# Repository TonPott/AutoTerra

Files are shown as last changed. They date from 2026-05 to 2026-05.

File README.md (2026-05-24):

# Automated Terrarium

Arduino Nano 33 IoT firmware project for an automated terrarium controller.

The controller is intended to monitor and control a terrarium with a small water feature. It communicates with Home Assistant over MQTT, while keeping essential hardware safety and fallback behavior local on the Arduino.

## Project Status

This repository is currently in the design and documentation phase.

Production firmware should not be implemented until the documentation set has been reviewed and accepted:

- `SPEC.md`
- `MODULES.md`
- `entity-model.md`
- `libraries.txt`
- `HA_DASHBOARD.md`
- `HA_AUTOMATIONS.md`
- `AGENTS.md`

The production firmware sketch lives under `sketches/AutoTerraController/` and is only a compileable placeholder at this stage.

## Main Goals

The controller shall:

- drive the terrarium light by IR remote commands,
- execute local fades between light presets,
- support manual light control, stand-alone light scheduling, and Home Assistant triggered scheduling,
- measure air temperature and humidity with a Sensirion SHT45,
- measure water temperature with a B3950 10K NTC thermistor,
- measure water level with a frequency-output liquid level sensor,
- control two Noctua 5 V PWM fans,
- monitor both fans by their tachometer outputs,
- locally shut down the pump on critical water level,
- verify simple light on/off state using a TCS34725 light sensor,
- keep time with a DS3231 RTC,
- store persistent configuration in the AT24C32 EEPROM on the RTC module,
- synchronize the RTC once per day from NTP,
- publish sensor values, state, availability, warnings, and faults to Home Assistant.

## Hardware Summary

Target board:

- Arduino Nano 33 IoT

Main external modules:

- DS3231 RTC module with AT24C32 EEPROM
- Sensirion SHT45 temperature/humidity sensor
- B3950 10K NTC thermistor for water temperature
- CQRobot multi-point photoelectric liquid level sensor with frequency output
- CQRobot/Adafruit-compatible TCS34725 light/color sensor
- two Noctua NF-A4x20 5V PWM fans with a shared transistor-buffered PWM line and separate tach inputs
- pump relay module using 3.3 V logic
- IR LED driver circuit for the remote-controlled lamp

## Documentation Map

- `SPEC.md` - complete functional specification
- `MODULES.md` - firmware module responsibilities and interfaces
- `entity-model.md` - Home Assistant entity model
- `HA_DASHBOARD.md` - initial dashboard design ideas
- `HA_AUTOMATIONS.md` - Home Assistant automation responsibilities
- `HARDWARE.md` - physical build, wiring, pin map, and signal-level overview
- `ROADMAP.md` - open tasks, validation work, risks, and implementation phases
- `DECISIONS.md` - accepted design decisions and rationale
- `AGENTS.md` - Codex working rules for this repository
- `libraries.txt` - required Arduino libraries and their roles
- `sketches/AutoTerraController/` - production firmware sketch and Arduino profile
- `hardware-tests/` - manual hardware validation sketches and test documentation

## Important Design Decisions

- The Arduino is the local hardware controller and safety layer.
- Home Assistant is the configuration, dashboard, and automation layer.
- The controller must remain locally safe when WiFi, MQTT, or Home Assistant is unavailable.
- Persistent data is read from EEPROM at boot and copied into RAM. During runtime, RAM is the active source of truth.
- EEPROM is written only when configuration or runtime recovery data changes.
- No custom MQTT payload model is planned for v1. Use ArduinoHA entities.
- Text-like status messages are allowed through a sensor entity because a separate test confirmed this works with the chosen Home Assistant setup.

## Local Setup

Arduino CLI setup is a one-time local machine preparation step. The setup
scripts prepare the shared Arduino CLI toolchain used by all AutoTerra
worktrees on the same machine.

Windows:

```powershell
.\scripts\setup-arduino.ps1
```

Linux / Codex Cloud / GitHub Actions:

```bash
./scripts/setup-arduino.sh
```

The setup scripts may use the network to update Arduino indexes, install the
Nano 33 IoT core, and install the libraries listed in
`sketches/AutoTerraController/sketch.yaml`.

By default, the shared Arduino CLI home is:

- Windows: `%LOCALAPPDATA%\AutoTerra\arduino-cli`
- Linux/macOS: `$HOME/.cache/autoterra/arduino-cli`

Set `AUTOTERRA_ARDUINO_HOME` to use a different shared toolchain location.
This directory is intentionally persistent across Codex worktrees.

## Compile Check

Compile checks should not download, install, or update anything. They generate
an ignored worktree-local Arduino CLI config at `.local/arduino-cli.yaml` that
points to the shared toolchain directories, then compile the selected sketch
with explicit ignored build output under `.build/` and build-cache configuration
pointing to `.arduino-cache/`.

Windows:

```powershell
.\scripts\check-arduino.ps1
```

Linux / Codex Cloud / GitHub Actions:

```bash
./scripts/check-arduino.sh
```

The active Arduino profile is `nano33iot` and targets `arduino:samd:nano_33_iot`.
Root compile checks use `sketches/AutoTerraController/` as the default production sketch. Hardware test sketches remain under `hardware-tests/` and can be compiled by setting `SKETCH=hardware-tests/<test-folder>`.

Windows hardware-test compile:

```powershell
$env:SKETCH = "hardware-tests/i2c-bus-scan"
.\scripts\check-arduino.ps1
```

Linux/macOS hardware-test compile:

```bash
SKETCH=hardware-tests/i2c-bus-scan ./scripts/check-arduino.sh
```

If a compile check reports that the Arduino toolchain is not prepared, run the
setup script once and retry the compile check.

## Cleanup

Worktree-local generated files can be removed safely with:

```powershell
.\scripts\cleanup-worktree.ps1
```

```bash
./scripts/cleanup-worktree.sh
```

The Codex App cleanup script, if configured, should use only the worktree
cleanup script. It removes `.build/`, `.arduino-cache/`, and `.local/` from the
current worktree and does not touch the shared Arduino CLI toolchain.

The shared Arduino CLI toolchain should not be removed by automatic Codex
cleanup. For manual project-end cleanup only, remove it with:

```powershell
.\scripts\cleanup-arduino-toolchain.ps1
```

```bash
./scripts/cleanup-arduino-toolchain.sh
```

These manual toolchain cleanup scripts ask for confirmation and warn that the
next setup will need to download cores and libraries again.

## Build Order

1. Finish and review documentation.
2. Create a small proof of concept for uncertain hardware or library behavior if needed.
3. Implement modules one by one.
4. Integrate Home Assistant entities.
5. Test safety and fallback behavior.
6. Tune dashboard and automations after firmware entities are stable.

Hardware tests and uploads are intentionally local tasks. CI and the provided scripts only verify that the firmware compiles.

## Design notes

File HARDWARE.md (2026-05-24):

# HARDWARE.md – Physical build and wiring overview

## Purpose

This document is the central physical wiring reference for AutoTerra.

It summarizes power domains, pin assignments, module wiring, and signal-level rules for building or reviewing the hardware. It does not replace the functional requirements in `SPEC.md`, the module responsibilities in `MODULES.md`, or the validation tracking in `ROADMAP.md`.

## System overview

Arduino Nano 33 IoT is the only target board.

The controller monitors and controls a terrarium with light, fans, water level, water temperature, air climate, RTC, EEPROM, pump relay, and Home Assistant connectivity.

The Arduino performs local hardware control and safety logic. Home Assistant provides configuration, dashboard, schedule triggers, and notifications, but pump safety and hardware-facing control remain local.

## Power domains

- A shared 5 V supply powers the fans and the Arduino Nano 33 IoT through VIN.
- All grounds must be common: supply GND, Nano GND, fan grounds, sensor grounds, relay module ground, and transistor emitter ground.
- Nano 33 IoT logic is 3.3 V.
- All signals connected directly to Nano pins must be 3.3 V compatible.
- SDA and SCL require effective pull-ups to 3.3 V.
- I2C pull-ups must not expose Nano pins to 5 V.
- The fan PWM line may be pulled up to 5 V only because it is isolated from the Nano GPIO by the 2N3904 transistor collector node.
- Fan tach pull-ups must go to 3.3 V.

## Complete pin map

```text
D2   DS3231 INT/SQW                 INPUT_PULLUP
D3   IR LED driver                  OUTPUT / handled by IRremote
D4   TCS34725 LED control           OUTPUT, default LOW = LED off, HIGH = LED on
D5   water level frequency input    INPUT_PULLUP
D6   shared fan PWM driver          OUTPUT, inverted through 2N3904
D7   TCS34725 INT                   INPUT_PULLUP, open-drain, optional / prepared
D8   DS3231 32kHz output            INPUT_PULLUP, optional / prepared
D9   fan 1 tach                     INPUT, external 10 kΩ pull-up to 3.3 V
D10  fan 2 tach                     INPUT, external 10 kΩ pull-up to 3.3 V
D11  pump relay control             OUTPUT, safe default pump off
A0   NTC water temperature          analog input
A4   I2C SDA                        DS3231 / AT24C32 / SHT45 / TCS34725
A5   I2C SCL                        DS3231 / AT24C32 / SHT45 / TCS34725
```

## I2C bus

The I2C bus is on A4/A5.

Devices on the bus:

- DS3231 RTC
- AT24C32 EEPROM on the RTC module
- SHT45 air temperature and humidity sensor
- TCS34725 light/color sensor

I2C addresses are validated during hardware and module tests. The SHT45 address may still be hardcoded in firmware later, but the tested hardware confirmed `0x44`.

### Confirmed I2C scan result

A manual I2C scan confirmed the expected external AutoTerra devices.

Confirmed external devices:

- `0x29` TCS34725 color/light sensor
- `0x44` SHT45 / SHT4x air temperature and humidity sensor
- `0x57` AT24C32 EEPROM
- `0x68` DS3231 RTC

Additional addresses seen on the Nano 33 IoT:

- `0x60` likely onboard ATECC608A secure element
- `0x6A` likely onboard LSM6DS3 IMU

These onboard addresses are expected on the Nano 33 IoT and should not be mistaken for extra external AutoTerra modules.

The bus must remain 3.3 V safe for the Nano 33 IoT.

- SDA and SCL require effective pull-ups to 3.3 V.
- The pull-ups may be provided by verified onboard module pull-ups or by external resistors.
- Do not use pull-ups to 5 V on SDA or SCL.
- If multiple breakout boards provide onboard pull-ups, verify the resulting effective pull-up resistance.
- External 4.7 kΩ pull-ups to 3.3 V are a typical starting point only if the bus does not already have suitable pull-ups.
- I2C module supply and pull-ups must not expose Nano pins to 5 V unless proper level shifting or isolation is used.

## Module wiring overview

| Module | Power | Signal pins | Notes |
|---|---|---|---|
| DS3231 + AT24C32 | 3.3 V safe module supply | A4 SDA, A5 SCL, D2 INT/SQW, D8 32kHz optional | RTC alarms use D2. AT24C32 shares I2C. D8 is prepared only. |
| SHT45 | 3.3 V safe module supply | A4 SDA, A5 SCL | Air temperature and humidity. Tested hardware confirmed address `0x44`; firmware may hardcode it later. |
| TCS34725 AngelTCS34725US / TCS34725FN | 3.3 V safe module supply | A4 SDA, A5 SCL, D4 LED, D7 INT optional | D4 LOW = LED off, HIGH = LED on. INT is open-drain and uses INPUT_PULLUP. |
| B3950 10K NTC | 3.3 V divider supply | A0 | 3.3 V -> 8.2 kΩ reference resistor -> A0 -> B3950 NTC -> GND. |
| CQRobot multi-point liquid level sensor | Sensor supply per module requirements, output must be 3.3 V safe | D5 | Frequency-output sensor, not I2C. D5 uses INPUT_PULLUP. |
| Two Noctua NF-A4x20 5V PWM fans | +5 V fan supply | D6 PWM driver, D9 fan 1 tach, D10 fan 2 tach | Shared 2N3904 PWM driver, separate tach inputs. |
| Pump relay module | Relay module supply per module requirements | D11 | D11 commands relay input. Safe default is pump off. |
| IR LED driver | Driver supply per circuit requirements | D3 | Driven by IRremote. Detailed driver circuit may be documented later. |

## Fan wiring

Fan power:

- both fan yellow wires connect to +5 V,
- both fan black wires connect to common GND.

Shared PWM driver:

- both blue PWM wires connect to the shared fan PWM collector node,
- the shared PWM collector node is pulled up to +5 V with 2.2 kΩ,
- D6 drives the 2N3904 base through 2.2 kΩ,
- 2N3904 emitter connects to GND,
- 2N3904 collector connects to the shared fan PWM node,
- 10 kΩ base pulldown connects base to GND,
- the driver is inverting.

Tach wiring:

- fan 1 green tach wire connects to D9,
- fan 2 green tach wire connects to D10,
- each tach line has its own 10 kΩ pull-up to 3.3 V,
- tach outputs must not be tied together,
- tach pull-ups must not connect to 5 V.

## Water level sensor wiring

- Signal output connects to D5.
- D5 is configured as INPUT_PULLUP.
- The sensor is a frequency-output sensor, not I2C.
- The sensor output connected to D5 must be 3.3 V compatible.

## Pump relay wiring

- Relay control input connects to D11.
- D11 is configured as OUTPUT.
- The safe default is pump off.
- Pump cutoff is local and latched.
- Firmware only commands the relay module.
- Mains wiring, isolation, enclosure, strain relief, and safety are hardware responsibilities.
- Do not assume a GPIO can drive a relay coil directly; the relay module must provide suitable driver circuitry.

## Light sensor wiring

The AngelTCS34725US / TCS34725FN module uses I2C plus LED and INT pins:

- SDA connects to A4,
- SCL connects to A5,
- LED control connects to D4,
- D4 HIGH = LED on,
- D4 LOW = LED off,
- INT connects to D7,
- INT is open-drain,
- D7 uses INPUT_PULLUP,
- INT is optional/prepared and not required for v1 logic.

## RTC and EEPROM wiring

- DS3231 and AT24C32 share I2C on A4/A5.
- DS3231 INT/SQW connects to D2 with INPUT_PULLUP.
- DS3231 32kHz output connects to D8 with INPUT_PULLUP.
- D8 is optional/prepared.
- No interrupt shall be attached to DS3231 32kHz in v1.

## Analog water temperature wiring

- B3950 10K NTC connects to A0 through a voltage divider.
- The divider uses an 8.2 kΩ upper reference resistor from 3.3 V to A0.
- The NTC divider is powered from the Nano 3.3 V domain.
- Nominal thermistor resistance is 10 kΩ.
- B value is 3950.
- Nominal temperature is 25 °C.
- AREF is not connected in v1.
- Do not connect an external 3.3 V reference to AREF unless the firmware explicitly configures and validates external analog reference use.

Wiring:

```text
3.3 V -> 8.2 kΩ -> A0 -> B3950 NTC -> GND
```

The 8.2 kΩ resistor is the upper reference leg, and the NTC is the lower leg to GND.

## IR output wiring

- IR LED driver is assigned to D3.
- D3 is handled by IRremote.
- The detailed IR LED driver circuit may be documented later if needed.
- Do not move D3 unless explicitly decided.

## Signal-level rules

- Nano 33 IoT GPIO is 3.3 V logic.
- Direct Nano inputs must not be pulled to 5 V.
- SDA and SCL require effective pull-ups to 3.3 V.
- I2C pull-ups must be 3.3 V safe and must not pull SDA or SCL to 5 V.
- External 4.7 kΩ pull-ups to 3.3 V are only a typical starting point when suitable onboard pull-ups are not already present.
- Fan tach pull-ups must be 3.3 V.
- Fan PWM pull-up may be 5 V only at the isolated transistor collector / fan PWM node.
- All grounds must be common.

## Safety notes

- Pump mains voltage must be treated as dangerous.
- Firmware documentation cannot replace safe electrical construction.
- Relay/contact rating is not the only safety requirement.
- Enclosure, isolation, strain relief, fuse/protection, cable routing, and legal/electrical safety rules must be handled outside firmware.

## Open hardware validation items

Relevant hardware checks are tracked in `ROADMAP.md`. The most important hardware-facing items are:

- 25 kHz fan PWM on Nano 33 IoT / SAMD21,
- fan PWM signal quality with both fans connected,
- fan tach readings,
- minimum fan PWM percent,
- PWM-to-RPM table,
- required water level sensor mounting height in the real tank,
- real levels for pump warning and stop,
- TCS34725 Clear-channel behavior in the actual room,
- DS3231 32kHz behavior if ever used,
- I2C bus voltage safety,
- relay wiring and mains safety.

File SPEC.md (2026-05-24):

# SPEC.md – Automated Terrarium

## 1. Scope

This document defines the target behavior of the terrarium controller firmware and its Home Assistant integration.

The project is based on an **Arduino Nano 33 IoT**. It shall operate as an autonomous hardware controller while using Home Assistant for configuration, dashboards, warnings, and scheduled events.

The document is written for a reader with beginner-to-intermediate Arduino and Home Assistant knowledge. It intentionally explains hardware roles, software behavior, and fallback cases in detail.

## 2. Core architecture

### 2.1 Normal operation

During normal operation:

- WiFi is connected.
- MQTT is connected.
- Home Assistant is available.
- The Arduino publishes all sensor and state values.
- Home Assistant provides configuration values.
- The Arduino still executes hardware-facing control locally.

At startup the Arduino shall:

1. initialize hardware modules,
2. read persistent configuration from AT24C32 EEPROM,
3. load configuration into RAM,
4. check RTC time,
5. attempt WiFi and MQTT connection,
6. publish current modes, sensor data, availability, and faults to Home Assistant,
7. resume a stored fade if applicable,
8. immediately evaluate pump safety.

### 2.2 Offline and fallback operation

If MQTT/Home Assistant is unavailable for **5 minutes**, the controller enters reduced stand-alone behavior.

In fallback mode:

- light uses the last stored stand-alone schedule,
- fan behavior uses the last stored fan mode and configuration,
- pump safety remains local,
- faults and counters are retained and republished after reconnect,
- configuration changes from Home Assistant are obviously unavailable.

Connectivity faults themselves are mostly handled in Home Assistant, but the Arduino shall maintain a connection drop / failed connection counter.

### 2.3 Timekeeping and time fallback

Primary time sources:

1. Home Assistant / NTP time
2. DS3231 RTC
3. RAM time snapshots plus uptime
4. simple timer fallback

The RTC shall be synchronized from NTP once per day. Home Assistant shall also expose a button to manually trigger synchronization.

Four times per day, the firmware shall store in RAM:

- a valid wall-clock timestamp from RTC or NTP,
- a corresponding runtime timestamp such as `millis()`.

If the RTC later fails, approximate current time can be reconstructed as:

```text
last_wall_clock_timestamp + elapsed_runtime_since_snapshot
```

If no valid RTC/NTP time is available for up to four days, this reconstructed time may be used. After four days without a valid time source, time-dependent light control falls back to a simple 24-hour timer:

```text
8 hours light using User Preset 2
16 hours off
repeat as a 24-hour cycle
```

This minimal time fallback affects light only. Safety functions such as pump cutoff and fan monitoring still run as far as their sensors allow.

## 3. Light system

### 3.1 Hardware

The terrarium lamp is controlled by IR commands that emulate the original remote control.

The existing IR LED uses pin **D3**.

IR command sending shall be non-blocking and buffered. Commands shall be spaced by a safe minimum interval.

### 3.2 Light modes

The light system has three modes:

```text
MANUAL
STANDALONE
HA_SCHEDULE
```

#### MANUAL

- Time schedules are stopped.
- Home Assistant directly controls the light.
- The Home Assistant frontend shall represent all required remote-control buttons.
- Not every button must be its own HA entity. It is acceptable to store IR commands in a named array and trigger array positions from HA buttons.
- Manual commands are not persistent.

If HA connection is lost, the next trigger starts from the current physical light state. If the Arduino restarts during manual mode and HA is unavailable, the controller uses the last applicable stand-alone preset.

#### STANDALONE

- Arduino runs a local two-event light schedule.
- Two times are configured from HA.
- Times are stored persistently in EEPROM.
- Times are also programmed into the DS3231 alarms.
- EEPROM configuration has priority over RTC alarm configuration during reconciliation.
- Day preset, night preset, and fade duration are configurable.
- Fades are calculated locally.
- If EEPROM is unavailable, hardcoded defaults with the same structure are used.

The DS3231 alarms are used for stand-alone mode only.

#### HA_SCHEDULE

Home Assistant sends scheduled light changes to the Arduino.

Each trigger contains:

- target preset,
- fade duration,
- trigger timestamp.

The Arduino:

- stores the command in RAM immediately,
- writes recovery data to EEPROM if available,
- computes and runs the fade locally,
- can resume or finish the fade after a restart.

If no fade was active before a restart, nothing is changed. The lamp is assumed to still be in its last physical state unless a fallback requires otherwise.

### 3.3 Manual override in schedule modes

Manual commands must also be possible in STANDALONE and HA_SCHEDULE.

Rules:

- a manual command interrupts any running fade,
- the manual light state remains until the next scheduled trigger,
- if the light is manually switched off, the next scheduled trigger must be able to switch it on again,
- manual commands are not persistent.

### 3.4 Preset model

Each RGBW channel has 10 steps:

```text
R: 0..10
G: 0..10
B: 0..10
W: 0..10
```

The firmware shall support:

- all factory presets,
- User Presets 1–4,
- dark/off,
- direct remote-control commands.

Some factory presets may be dynamic in the real lamp. For local fade calculation they shall be modeled as static RGBW values.

Required tables:

- static table for factory presets,
- mutable table for user presets,
- IR command table for remote-control simulation.

## 4. Light verification sensor

A TCS34725 light/color sensor is used to verify whether the lamp is broadly on or off.

The AngelTCS34725US / TCS34725FN module is connected through I2C and power, and also uses prepared optional signal pins:

- TCS34725 LED control is wired to Arduino D4,
- D4 shall be configured as `OUTPUT`,
- D4 LOW means sensor LED off,
- D4 HIGH means sensor LED on,
- the default firmware state shall keep the sensor LED off unless a measurement mode explicitly enables it,
- normal light on/off verification shall use a defined LED state, initially LED off,
- TCS34725 INT is wired to Arduino D7 and prepared for optional future use,
- the TCS34725 INT output is open-drain,
- D7 shall be configured as `INPUT_PULLUP`,
- TCS34725 INT is not required for v1 logic; v1 uses periodic and event-triggered measurements.

First firmware version:

- no full color validation,
- use the **Clear raw value** as the first on/off indicator,
- global calibration only,
- two reference values:
  - light off reference,
  - minimum on reference,
- allowed deviation: 5%.

Measurement shall happen:

- periodically,
- at fade start,
- when a target preset is reached,
- on light mode changes.

Home Assistant shall provide buttons to store the current Clear value as the off or minimum-on reference.

A light expected/actual mismatch is detected in the Arduino and reported to Home Assistant.

The room contains daylight and a ceiling light, so the TCS34725 check may be unreliable. In v1, warnings shall still be published so the behavior can be evaluated.

## 5. Climate sensor: SHT45

The SHT45 replaces the earlier SHT31 design.

Important differences:

- no hardware alert pin,
- no SHT31-style alert registers,
- thresholds are evaluated in firmware.

Requirements:

- use Sensirion arduino-i2c-sht4x library,
- SHT45 I²C address will be hardcoded later,
- measure about twice per minute,
- publish values at least once per minute,
- publish air temperature with one decimal place,
- publish humidity,
- detect and report communication or sensor errors if possible,
- mark SHT45-related entities unavailable when the sensor is unavailable.

SHT45 heater usage is not defined for v1. It remains a documented option for later evaluation, e.g. for condensation recovery, self-drying, or diagnostics.

## 6. Fan control

### 6.1 Hardware

Two Noctua NF-A4x20 5V PWM fans are used.

Design:

- one shared PWM output controls both fans,
- two tach inputs are measured separately,
- PWM driver circuit uses an inverting 2N3904 NPN transistor stage,
- tach signals are open collector,
- tach inputs use separate external 10 kΩ pull-ups to 3.3 V.

#### 6.1.1 Fan supply wiring

Both fans are powered directly from the shared 5 V supply:

- fan yellow wires connect to the +5 V supply,
- fan black wires connect to common GND,
- Arduino Nano 33 IoT is powered from the same 5 V supply through VIN.

All grounds must be common: power supply GND, Nano GND, both fan grounds, and the 2N3904 emitter.

Two NF-A4x20 5V PWM fans need about 0.2 A maximum for the fans alone. The power supply must also reserve current for the Nano, sensors, relay module, startup transients, and load peaks.

A local bulk capacitor on the 5 V rail, for example 100 µF near the fan or power distribution point, is recommended as hardware decoupling. This is not a firmware requirement.

#### 6.1.2 Shared fan PWM driver

The shared fan PWM line is driven by a 2N3904 used as an NPN open-collector style driver:

- Nano D6 connects through a 2.2 kΩ base resistor to the 2N3904 base,
- 2N3904 emitter connects to GND,
- 2N3904 collector connects to the shared fan PWM node,
- the blue PWM wires of both fans connect to this shared collector node,
- the shared fan PWM node has an external 2.2 kΩ pull-up to +5 V,
- an optional 10 kΩ base pulldown from base to GND may be used so the transistor stays off during reset.

This circuit intentionally inverts the PWM signal:

- Arduino output high -> transistor on -> fan PWM line low,
- Arduino output low or high-Z during reset -> transistor off -> fan PWM line pulled high.

Therefore `FanControl` must continue to convert effective fan percent to inverted PWM hardware duty.

The external 2.2 kΩ pull-up is intentional so the PWM line has defined edges with both fans connected and the Nano GPIO does not directly drive or sink both fan PWM inputs. The 5 V PWM line exists only at the fan PWM inputs, the pull-up, and the transistor collector. It must not be directly connected to a Nano input or output pin.

#### 6.1.3 Separate RPM/tach wiring

The fan tach signals are wired separately:

- fan 1 green tach wire connects to D9,
- fan 2 green tach wire connects to D10,
- each tach line has its own external 10 kΩ pull-up to 3.3 V,
- tach outputs must not be tied together,
- tach pull-ups must not connect to 5 V.

The tach outputs are open collector. With 3.3 V pull-ups they are compatible with Nano 33 IoT inputs.

RPM calculation should assume two pulses per revolution unless later hardware testing proves otherwise. D9 and D10 must be used as interrupt-capable or otherwise reliably sampled tach inputs according to the final Nano 33 IoT implementation approach.

#### 6.1.4 PWM frequency

Fan PWM shall target the Noctua / 4-pin-PWM typical high-frequency range around 25 kHz. The timer configuration for Nano 33 IoT / SAMD21 must be implemented intentionally; default `analogWrite()` behavior must not be assumed to produce the required fan-control frequency. The implementation must verify the actual PWM frequency during hardware bring-up.

#### 6.1.5 Protection and level notes

- Tach pull-ups go to 3.3 V to protect Nano inputs.
- The fan PWM pull-up goes to 5 V because it is a fan-control line driven only through the transistor collector and not directly connected to a Nano input or output.
- Do not connect fan tach outputs to 5 V pull-ups.
- Do not drive two fan PWM inputs directly from the Nano GPIO in this design.
- Keep common ground between Arduino and fan supply.

The firmware shall operate in effective fan percentage:

```text
0% = off
100% = full fan output
```

The hardware driver converts effective percentage to the inverted raw PWM output.

Example:

```text
effective 0%   -> hardware duty 100%
effective 40%  -> hardware duty 60%
effective 100% -> hardware duty 0%
```

The `FanControl` hardware layer shall account for the inverting driver and expose only effective fan percentage to the rest of the firmware.

### 6.2 Fan modes

Fan control has its own persistent mode:

```text
AUTO
MANUAL
```

#### AUTO

The Arduino computes fan speed locally from two four-point curves:

- air temperature to fan percent,
- air humidity to fan percent.

The higher computed value wins.

Curve behavior:

- below point 1: 0%,
- between points: linear interpolation,
- above point 4: constant at point 4 output.

Default temperature curve:

```text
26 °C -> 0%
28 °C -> 20%
30 °C -> 35%
33 °C -> 50%
```

Default humidity curve:

```text
50 %RH -> 0%
65 %RH -> 20%
75 %RH -> 30%
90 %RH -> 50%
```

#### MANUAL

Home Assistant sets the fan percentage directly.

Manual fan mode requirements:

- the mode is persistent,
- the last manual percent is persistent,
- the mode is retained during HA/MQTT loss,
- sensor faults are reported but do not automatically override manual mode to 100%.

### 6.3 Fan diagnostics

The firmware shall publish:

- shared effective fan PWM percent,
- fan 1 RPM,
- fan 2 RPM,
- fan 1 fault,
- fan 2 fault,
- optional RPM mismatch warning.

A fixed calibration table will be provided later:

```text
effective PWM percent -> expected RPM
```

The table applies to both fans initially and is not editable from Home Assistant.

Minimum PWM starts at 15% and must be evaluated in real hardware.

No automatic fan restart sequence is required.

## 7. Water temperature

A B3950 10K NTC thermistor measures water temperature.

Requirements:

- connected to A0 analog input,
- B3950 10K NTC voltage divider documented in `HARDWARE.md`,
- nominal thermistor resistance: 10 kΩ,
- B value: 3950,
- nominal temperature: 25 °C,
- use NTC_Thermistor library,
- publish all available temperature units:
  - Celsius,
  - Fahrenheit,
  - Kelvin.

The frontend later decides which value is displayed.

## 8. Water level

### 8.1 Sensor

The liquid level sensor is **not I²C-based**. It outputs a square wave.

Nominal frequencies:

```text
without liquid: 20 Hz
Level 1:        50 Hz
Level 2:       100 Hz
Level 3:       200 Hz
Level 4:       400 Hz
```

The sensor shall be read using a digital interrupt-capable input with INPUT_PULLUP.

The assigned pin is **D5**, because D2 is used for RTC interrupt and D3 is used for IR.

### 8.2 Measurement and publication

The level is evaluated once per minute.

Normal HA publication:

- water level in mm.

Optional diagnostics during setup, calibration, or troubleshooting:

- internal level,
- raw frequency.

Raw frequency is not required for the normal dashboard and should not be considered part of the regular user-facing entity set unless calibration or troubleshooting requires it.

### 8.3 Mechanical calibration

Home Assistant configures the distance from sensor top edge to tank bottom. This value must be stored in Arduino EEPROM because the Arduino calculates the water height.

Sensor geometry:

```text
total sensor height: 78.2 mm
Level 4 is 24.4 mm below sensor top edge
each lower level is 16 mm below the previous one
```

Pump cutoff is based on **level**, not mm.

### 8.4 Stability rule

Level changes between noncritical levels are debounced over a long period.

Example:

- official level is Level 4,
- Level 3 is measured,
- timestamp is stored,
- if Level 4 is measured again, the Level 3 candidate is discarded,
- if Level 4 is not measured for 6 hours, Level 3 becomes official.

Exception:

- without liquid / 20 Hz triggers pump cutoff immediately.

Leak warning:

- if the next lower level is reached during the 6-hour waiting period, publish a possible leak / fast-loss warning to Home Assistant.

## 9. Pump safety

The relay module is considered Arduino-ready and uses 3.3 V logic.

The pump is controlled locally for safety.

Rules:

- critical water level immediately shuts off pump,
- pump cutoff is latched,
- no automatic restart after cutoff,
- manual release is required,
- when water level sensor is unavailable, pump is turned off,
- Home Assistant may manually re-enable the pump despite sensor unavailability,
- this sensor-failure override is **not persistent**,
- after every Arduino restart, the user must confirm pump enable again while the sensor remains unavailable.

Home Assistant shall show a visible warning next to the pump switch when the water level sensor is unavailable.

Mains voltage safety must be documented separately. The firmware can command the relay, but safe wiring, isolation, enclosure, and strain relief are hardware requirements.

## 10. RTC and EEPROM

### 10.1 DS3231

The DS3231 provides local time and two alarms.

Requirements:

- DS3231 INT/SQW pin uses INPUT_PULLUP,
- assigned pin: D2,
- DS3231 INT/SQW remains on D2 and is used for stand-alone alarm triggers,
- DS3231 32kHz output is wired to Arduino D8 and prepared for optional future use,
- D8 shall be configured as INPUT_PULLUP,
- the 32kHz signal is not used by v1 logic and no interrupt shall be attached by default,
- if 32kHz is enabled later, it must be handled carefully because it is a high-frequency signal,
- alarms are used for stand-alone light mode,
- RTC is synchronized from NTP daily,
- HA exposes a manual sync button.

### 10.2 AT24C32 EEPROM

The AT24C32 is accessed using JC_EEPROM.

Design rule:

```text
EEPROM is persistent storage.
RAM is the active runtime source of truth.
```

At boot:

- read EEPROM,
- validate minimal header,
- copy data to RAM.

At runtime:

- use RAM values,
- update RAM immediately on HA changes,
- write EEPROM only when configuration or recovery data changes.

If EEPROM becomes unavailable during operation:

- report error,
- continue with RAM configuration.

If EEPROM is unavailable at boot:

- use hardcoded defaults,
- accept HA configuration if HA becomes available,
- operate non-persistently until EEPROM recovers.

### 10.3 EEPROM validation

Use a minimal header only:

```text
magic
version
length
```

No CRC.

Reason:

- CRC would be stored in the same EEPROM and may itself be corrupted,
- false invalidation of otherwise valid data is possible,
- implementation complexity is not justified for v1.

Use two logical blobs:

- Config blob,
- Runtime blob.

## 11. Persistence data

### 11.1 Persistent configuration

Store:

- light mode,
- fan mode,
- last manual fan percent,
- stand-alone schedule times,
- stand-alone day/night presets,
- stand-alone fade duration,
- fan curves,
- minimum PWM,
- temperature warning thresholds,
- water level calibration,
- pump cutoff threshold / level,
- light sensor calibration values,
- user presets.

### 11.2 Runtime recovery data

Store:

- whether a fade is active,
- fade start time,
- fade duration,
- fade start state,
- fade target state,
- last relevant light state,
- last valid time snapshot if needed,
- offline fault counters if HA was unreachable.

### 11.3 Not persistent

Do not persist:

- regular sensor measurements,
- debug flag,
- one-off manual light commands,
- pump sensor-failure override,
- transient runtime states not needed for recovery.

## 12. Faults, warnings, diagnostics, and availability

### 12.1 Definitions

A fault is a state that affects local operation or disables a module.

A warning is a state that should be visible but may not require local intervention.

A diagnostic value explains system state.

### 12.2 Self-diagnosis

Each module shall provide a health / availability state.

I²C problems are detected by checking each I²C transaction or module library return value. A central I²C health check may also be added, but individual module checks remain required.

When a module is known to be unavailable, its corresponding HA entities shall be marked unavailable if the chosen entity type supports availability.

### 12.3 Fault examples

Faults:

- SHT45 unavailable,
- RTC unavailable,
- EEPROM unavailable,
- TCS34725 unavailable,
- NTC open/short/unavailable,
- water level sensor unavailable,
- pump cutoff active,
- fan 0 RPM while expected to run.

Warnings:

- light expected/actual mismatch,
- water level one level before critical,
- RPM mismatch,
- water temperature limits,
- fast water-level drop.

Diagnostics:

- last time sync source,
- last time sync age,
- connection drop counter,
- fallback mode,
- module availability.

Hardware fault entities must not be automatically cleared only because HA reconnects. Current fault state must be republished after reconnect.

## 13. Home Assistant role

Home Assistant is responsible for:

- configuration,
- dashboards,
- warnings/notifications,
- HA schedule mode,
- water-level calibration,
- light sensor calibration,
- RTC manual sync button.

Home Assistant automations handle:

- HA light schedule triggers,
- calibration workflows,
- warning notifications,
- frontend display.

The Arduino remains responsible for:

- hardware signal processing,
- pump safety,
- fan PWM generation and RPM measurement,
- light IR output,
- local fades,
- fallback behavior.

No custom MQTT payload model shall be used in v1. Use ArduinoHA entities.

A previous isolated test confirmed that a sensor entity can be used successfully for text-like status output with the selected ArduinoHA setup.

## 14. Suggested pin map

```text
D2   DS3231 INT/SQW                 INPUT_PULLUP
D3   IR LED driver                  OUTPUT / handled by IRremote
D4   TCS34725 LED control           OUTPUT, default LOW = LED off, HIGH = LED on
D5   water level frequency input    INPUT_PULLUP
D6   shared fan PWM driver          OUTPUT, inverted through 2N3904
D7   TCS34725 INT                   INPUT_PULLUP, open-drain, optional / prepared
D8   DS3231 32kHz output            INPUT_PULLUP, optional / prepared
D9   fan 1 tach                     INPUT, external 10 kΩ pull-up to 3.3 V
D10  fan 2 tach                     INPUT, external 10 kΩ pull-up to 3.3 V
D11  pump relay control             OUTPUT, safe default pump off
A0   NTC water temperature          analog input
A4   I2C SDA                        DS3231 / AT24C32 / SHT45 / TCS34725
A5   I2C SCL                        DS3231 / AT24C32 / SHT45 / TCS34725
```

This is the current intended pin map. Pin assignments may change only through an explicit design update.

General hardware note:

- all logic signals connected directly to the Nano 33 IoT must be 3.3 V compatible,
- I2C bus must be 3.3 V safe and must have effective pull-ups to 3.3 V,
- I2C module supply and pull-ups must not expose Nano pins to 5 V unless proper level shifting or isolation is used.

## 15. Documentation-first implementation rule

Before firmware implementation, generate and review:

- `SPEC.md`,
- `MODULES.md`,
- `entity-model.md`,
- `AGENTS.md`,
- `libraries.txt`,
- `HA_DASHBOARD.md`,
- `HA_AUTOMATIONS.md`.

`Credentials.example.h` is created together with the first WiFi/MQTT implementation. It should contain only credentials that are actually needed by the implemented connectivity layer. Until connectivity code exists, credential fields should not be guessed.

Firmware implementation starts only after the documentation is accepted.

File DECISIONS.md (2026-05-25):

# DECISIONS.md – AutoTerra design decisions

## Purpose

This document records important AutoTerra design decisions and the reasoning behind them.

It is not a commit changelog. It exists to help future contributors understand why the current design is shaped the way it is.

## Decision format

Decision entries use this structure:

Title line:
`## YYYY-MM-DD – Decision title`

Status:
`Accepted`

Decision:
A short description of the decision.

Reason:
Why this decision was made.

Consequences:
What this means for the project.

## Accepted decisions

## 2026-05-16 – Documentation-first workflow before firmware implementation

Status:
Accepted

Decision:
AutoTerra will complete and review the core documentation set before production firmware implementation starts.

Reason:
The controller combines hardware safety, persistence, Home Assistant integration, fallback behavior, and several sensors. Defining the intended behavior first reduces accidental implementation drift.

Consequences:
Firmware work must follow `SPEC.md`, `MODULES.md`, `entity-model.md`, `libraries.txt`, `HA_DASHBOARD.md`, `HA_AUTOMATIONS.md`, and `AGENTS.md`. Open work and validation tasks belong in `ROADMAP.md`.

## 2026-05-16 – Arduino Nano 33 IoT as the only target board

Status:
Accepted

Decision:
The only target board for v1 is Arduino Nano 33 IoT.

Reason:
The selected hardware, WiFi support, pin plan, and SAMD21 behavior are specific to this board.

Consequences:
No AVR, Arduino Mega, or generic compatibility layer should be added unless the decision is explicitly revisited.

## 2026-05-16 – SHT45 replaces SHT31; no hardware alert mode

Status:
Accepted

Decision:
AutoTerra uses the Sensirion SHT45 for air temperature and humidity, and does not use SHT31-style hardware alert mode.

Reason:
The selected SHT45 design does not provide the earlier SHT31 alert-register workflow.

Consequences:
Threshold evaluation and fault reporting belong in firmware logic, not hardware alert pins or SHT31 alert registers.

## 2026-05-16 – Home Assistant handles configuration and dashboards; Arduino keeps local hardware safety

Status:
Accepted

Decision:
Home Assistant is responsible for configuration, dashboards, notifications, and schedule triggers, while the Arduino remains responsible for local hardware safety and fallback behavior.

Reason:
The controller must remain safe when WiFi, MQTT, or Home Assistant is unavailable.

Consequences:
Pump cutoff, sensor reads, fan PWM generation, RPM measurement, IR output, local fades, and fallback logic must run locally on the Arduino.

## 2026-05-16 – No custom MQTT payload model for v1; use ArduinoHA entities

Status:
Accepted

Decision:
AutoTerra v1 will use ArduinoHA entities instead of a custom MQTT payload architecture.

Reason:
ArduinoHA provides Home Assistant discovery and entity abstractions that match the intended integration model.

Consequences:
Entity design belongs in `entity-model.md`. Fan curves and configuration values may use multiple standard entities rather than custom packed MQTT payloads.

## 2026-05-16 – Text-like status output via sensor entity is accepted

Status:
Accepted

Decision:
Text-like status output through a sensor entity is accepted for v1.

Reason:
A separate proof-of-concept test confirmed that this works in the selected Home Assistant setup.

Consequences:
The firmware may expose system status text through an ArduinoHA sensor entity, and this premise should be preserved in documentation.

## 2026-05-16 – AT24C32 EEPROM is persistent storage; RAM is runtime source of truth

Status:
Accepted

Decision:
The AT24C32 EEPROM stores persistent configuration and recovery data, but RAM is the active source of truth after boot.

Reason:
Constant EEPROM reads are unnecessary and would make runtime behavior more fragile and slower.

Consequences:
The firmware reads EEPROM at boot, copies valid data into RAM, updates RAM immediately on changes, and writes EEPROM only when persistent data changes.

## 2026-05-16 – EEPROM validation uses magic, version, and length, but no CRC

Status:
Accepted

Decision:
EEPROM blobs use minimal validation fields: `magic`, `version`, and `length`. CRC is not used for v1.

Reason:
A CRC stored in the same EEPROM can itself be corrupted, and the extra complexity is not justified for the first version.

Consequences:
The firmware should reject obviously incompatible blobs but should not implement CRC validation unless this decision is revisited.

## 2026-05-16 – Persistent storage uses a config blob and a runtime blob

Status:
Accepted

Decision:
Persistent storage is split into a configuration blob and a runtime recovery blob.

Reason:
Long-lived user configuration and short-lived recovery state have different lifecycles and should not be conflated.

Consequences:
Persistence code must keep configuration values separate from fade recovery, time snapshots, and other runtime recovery data.

## 2026-05-16 – Fan control supports AUTO and MANUAL modes with persistent manual settings

Status:
Accepted

Decision:
Fan control supports AUTO and MANUAL modes. Fan mode and manual fan percent are persistent.

Reason:
Manual fan control must remain predictable during Home Assistant or MQTT loss.

Consequences:
The firmware must retain manual fan mode and the last manual percent across restart and communication loss.

## 2026-05-16 – Fan PWM uses an inverting 2N3904 driver and effective fan percent

Status:
Accepted

Decision:
Internal fan logic uses effective fan percent, while `FanControl` converts that value to the inverted PWM duty required by the external driver circuit. The shared fan PWM signal is driven through an inverting 2N3904 NPN transistor stage. The shared fan PWM node uses a 2.2 kΩ pull-up to +5 V, and the Nano GPIO must not directly drive the two fan PWM inputs. Fan tach pull-ups are separate 10 kΩ resistors to 3.3 V.

Reason:
The transistor stage protects the Nano GPIO from the 5 V fan PWM line, supports both fan PWM inputs from one shared signal, and keeps inversion isolated at the hardware boundary.

Consequences:
`FanControl` owns the conversion from effective fan percent to inverted PWM hardware duty. Tach inputs remain separate and use 3.3 V pull-ups to protect Nano inputs.

## 2026-05-25 – Use analogWrite-based fan PWM for v1

Status:
Accepted

Decision:
AutoTerra v1 uses Arduino `analogWrite()`-based fan PWM on D6 through the inverting 2N3904 driver.

Reason:
`analogWrite()`-based PWM worked reliably with the inverting 2N3904 driver, and both fan tach inputs worked. Manual hardware tests measured minimum startup and minimum stable running values. A/B testing showed no audible difference between `analogWrite()` and approximately 25 kHz PWM. The approximately 25 kHz mode requires taking ownership of TCC0 on the Nano 33 IoT, changes the PWM-to-RPM response, and would require separate calibration.

Consequences:
The v1 fan calibration table is based on `analogWrite()` results. Custom approximately 25 kHz fan PWM remains a future option. If approximately 25 kHz PWM is enabled later, the fan calibration table must be repeated or confirmed. TCC0 ownership and IR regression testing remain relevant only if approximately 25 kHz PWM is adopted later.

## 2026-05-16 – SHT/I²C errors do not automatically force MANUAL fan mode to 100%

Status:
Accepted

Decision:
SHT or I²C errors are reported, but they do not automatically override MANUAL fan mode to 100%.

Reason:
Manual fan mode is an intentional user-controlled state and should not be unexpectedly replaced by fault behavior unless requirements change.

Consequences:
Faults must be visible in Home Assistant, but MANUAL fan mode remains manual during these errors.

## 2026-05-16 – Pump cutoff is local and latched; sensor-failure override is not persistent

Status:
Accepted

Decision:
Pump cutoff is enforced locally and latched. Home Assistant may manually re-enable the pump during water sensor failure, but that override is not persistent.

Reason:
Pump safety must not depend on network availability, and sensor-failure override should require conscious confirmation after every restart.

Consequences:
The firmware must not auto-restart the pump after cutoff and must clear sensor-failure override on Arduino restart.

## 2026-05-16 – Water level downward changes use 6-hour stabilization except without liquid

Status:
Accepted

Decision:
Official downward changes between noncritical water levels require a 6-hour stabilization period, while `without liquid` triggers immediate pump cutoff.

Reason:
Normal water movement may cause transient lower readings, but no-liquid state is safety-critical.

Consequences:
`LiquidSensor` must track candidate lower levels over time and `PumpSafety` must react immediately to `without liquid`.

## 2026-05-16 – Light fallback without valid time uses 8 h User Preset 2 and 16 h off

Status:
Accepted

Decision:
If no valid time source is available beyond the allowed fallback period, light control uses an 8-hour on / 16-hour off timer with User Preset 2.

Reason:
The terrarium should retain a simple, predictable light cycle even without RTC, NTP, or Home Assistant time.

Consequences:
This minimal timer fallback applies to light behavior only and does not replace other safety logic.

## 2026-05-16 – TCS34725 v1 uses global Clear-channel on/off validation only

Status:
Accepted

Decision:
The first TCS34725 implementation uses the Clear raw channel for broad light on/off validation, not full color validation.

Reason:
Room daylight and ceiling light may make full validation unreliable, and the first version only needs a broad expected/actual mismatch check.

Consequences:
Firmware should publish warnings for mismatches, but full RGB/lux/color-temperature validation is deferred.

## 2026-05-16 – Credentials example is deferred until first WiFi/MQTT implementation

Status:
Accepted

Decision:
`Credentials.example.h` will be created with the first WiFi/MQTT implementation, not during documentation-only setup.

Reason:
The exact credential structure should follow the actual WiFi and MQTT implementation interfaces. Until connectivity code exists, credential fields should not be guessed.

Consequences:
Documentation may mention the planned credentials example, but this documentation-only phase does not need to create it yet. The file should contain only credentials that are actually needed by the implemented connectivity layer.

## 2026-05-17 – Optional TCS34725 and DS3231 signal lines are wired and reserved from the start

Status:
Accepted

Decision:
Optional TCS34725 LED/INT and DS3231 32kHz lines are wired and reserved from the start. D4 is TCS34725 LED control with LOW = LED off and HIGH = LED on. D7 is TCS34725 INT prepared input with `INPUT_PULLUP` because INT is open-drain. D8 is DS3231 32kHz prepared input with `INPUT_PULLUP`.

Reason:
Wiring optional signals from the start avoids later rewiring if these functions become useful during calibration, diagnostics, or future firmware versions.

Consequences:
These functions may be initialized safely even when not actively used in v1. TCS34725 INT and DS3231 32kHz remain optional prepared inputs; v1 does not depend on them.

## Superseded decisions

No superseded decisions are recorded yet.

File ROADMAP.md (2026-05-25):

# ROADMAP.md – AutoTerra implementation roadmap

## Purpose

This document tracks open tasks, validation work, implementation phases, known risks, and deferred decisions for AutoTerra.

It does not redefine current requirements. The target behavior remains documented in `SPEC.md`, `MODULES.md`, `entity-model.md`, `HA_DASHBOARD.md`, `HA_AUTOMATIONS.md`, and `libraries.txt`.

## Documentation phase

- Keep `SPEC.md`, `MODULES.md`, and `entity-model.md` as current target-state documents.
- Keep `AGENTS.md` as Codex working rules.
- Keep `README.md` as the project overview and documentation map.
- Keep `DECISIONS.md` as the accepted design rationale and design history.
- Avoid scattering TODOs inside requirement documents when a task belongs in `ROADMAP.md`.
- Move validation tasks, open implementation work, known risks, and deferred decisions into this document unless the uncertainty is itself part of the requirement.

## Pre-implementation validation tasks

- Verify ArduinoHA text-like sensor behavior is already completed successfully, but keep the result documented as an accepted premise.
- Confirm that fan PWM driver inversion is handled only inside `FanControl`.
- Use the first `hardware-tests/fan-pwm-tach` sketch to validate wiring, driver inversion, and tach reading with `analogWrite()` only.
- Use the separate `hardware-tests/fan-pwm-calibration` sketch to collect minimum startup, minimum stable running, and 5%-step `analogWrite()` RPM data.
- Use the separate `hardware-tests/fan-pwm-frequency-ab` sketch to compare Arduino `analogWrite()` with approximately 25 kHz PWM when the local D6 timer setup is safe.
- Validate that the selected ArduinoHA entity types work as expected for fan, select, number, binary sensor, button, switch, and text-like sensor output.
- Validate integrated RTC scheduling behavior around RTClib alarms after `RtcClock` is implemented.
- Confirm the final pin map against the real hardware layout before firmware implementation.
- Verify whether normal light verification should run with the TCS34725 LED off, on, or in a controlled measurement sequence.
- Verify TCS34725 INT behavior on D7 if future threshold or interrupt use is desired.
- Verify DS3231 32kHz output behavior on D8 before using it for timing or diagnostics.
- Confirm that no connected module exposes Nano 33 IoT pins to 5 V logic levels.
- Revisit `NTC_Thermistor` version selection when version 2.1.1 or later is available through Arduino Library Manager.
- Create `Credentials.example.h` together with the first WiFi/MQTT implementation.
- Ensure `Credentials.example.h` contains only credentials that are actually needed by the implemented connectivity layer.
- Do not guess credential fields before connectivity code exists.

## Firmware implementation phases

- Phase 1: compileable project skeleton under `sketches/AutoTerraController/`.
- Phase 2: infrastructure modules: Debug, Config, Types, TimeSync, Persistence.
- Phase 3: sensor modules: SHT45, NTC, LiquidSensor, TCS34725.
- Phase 4: actuator modules: IRControl, Fade, LightRuntime, FanControl, PumpSafety.
- Phase 5: HomeAssistantBridge entities and command handling.
- Phase 6: fault handling, fallback behavior, reconnect republishing.
- Phase 7: integration testing and dashboard/automation refinement.

## Hardware validation tasks

- Manual hardware validation sketches and test documentation live under [`hardware-tests/`](hardware-tests/README.md).
- Integrate the v1 fan PWM-to-RPM calibration table from the accepted `analogWrite()` results.
- Test fan tach readings with separate external 10 kΩ pull-ups to 3.3 V.
- Test the water level sensor frequencies in the real tank.
- Evaluate the 6-hour stabilization rule with the real water surface behavior.
- Test the immediate pump cutoff at the `without liquid` level.
- Test the TCS34725 Clear-channel light on/off detection in the actual room.
- Test NTC readings with the chosen 8.2 kΩ reference resistor voltage divider.
- Evaluate analog reference strategy only if NTC readings show unacceptable noise or drift.
- Confirm relay module wiring and mains safety outside firmware scope.

## Validated findings

- Manual I2C bus scan completed successfully.
- Confirmed external I2C addresses:
  - `0x29` TCS34725 color/light sensor
  - `0x44` SHT45 / SHT4x air temperature and humidity sensor
  - `0x57` AT24C32 EEPROM
  - `0x68` DS3231 RTC
- Observed expected onboard Nano 33 IoT I2C addresses:
  - `0x60` likely ATECC608A secure element
  - `0x6A` likely LSM6DS3 IMU
- I2C voltage-safety validation remains separate from the successful bus scan unless SDA/SCL levels are measured directly.
- Manual fan PWM/tach `analogWrite()` bring-up completed successfully.
- Confirmed D6 inverting fan PWM control behavior, separate D9/D10 tach interrupt readings, and plausible RPM measurements for both Noctua NF-A4x20 5V PWM fans.
- Observed effective 0% stopping both fans after spin-down and effective 100% producing approximately 4,860-5,040 RPM across the two fans in the initial run.
- Manual fan PWM calibration `analogWrite()` run completed successfully.
- Observed analogWrite-based minimum startup for both fans at 10% effective PWM; fan 1 alone started at 8%, fan 2 did not.
- Observed analogWrite-based minimum stable running for both fans at 8% effective PWM after spin-up; fan 1 alone kept running at 5%, fan 2 did not.
- Collected 5%-step analogWrite-based RPM data from 0% through 100%; this data is documented in `hardware-tests/fan-pwm-calibration/README.md`.
- Manual fan PWM frequency A/B test completed successfully in both `analogWrite()` and local approximately 25 kHz TCC0 modes.
- Observed approximately 25 kHz mode producing lower RPM than `analogWrite()` through much of the low-to-mid range, similar RPM at 75%, and slightly higher RPM at 100% in the A/B run.
- Observed no audible difference in sound profile or volume between `analogWrite()` and approximately 25 kHz PWM during the A/B test.
- v1 decision: `analogWrite()`-based fan PWM is accepted.
- Custom approximately 25 kHz fan PWM remains a future option only if noise or compatibility problems appear.
- Manual DS3231 + AT24C32 test completed successfully.
- Confirmed DS3231 RTC time readout, RTClib Alarm1 setup, Alarm1 flag reporting, D2 INT/SQW active-LOW alarm behavior, and D2 returning HIGH after clearing and disabling Alarm1.
- Confirmed AT24C32 EEPROM write/read verification at test offset `0x0F00`.
- Observed D8 32kHz prepared input as HIGH during the test; 32kHz pulse counting was intentionally not performed.

## Home Assistant validation tasks

- Validate MQTT discovery behavior for all planned ArduinoHA entities.
- Validate fan, select, number, binary sensor, button, and switch entities in the target Home Assistant installation.
- Validate text-like status output through a sensor entity remains reliable after integration.
- Validate state republishing after MQTT reconnect.
- Validate that module availability and fault entities behave clearly in the dashboard.
- Validate the pump sensor-failure warning near the pump control before allowing manual override workflows.
- Defer final Lovelace dashboard and automation YAML until entity names and types are stable.

## Known technical risks

- Custom approximately 25 kHz fan PWM would require low-level timer configuration and TCC0 ownership if revisited.
- TCS34725 on/off detection may be unreliable due to daylight and room lighting.
- Water level signal may fluctuate because of pump-induced waves.
- EEPROM is not continuously read during runtime; RAM is the source of truth after boot.
- `NTC_Thermistor` version selection may need revisiting.
- Production RTC scheduling still needs integrated validation even though the standalone RTClib Alarm1 / D2 behavior passed.
- ArduinoHA entity behavior may differ between simple proof-of-concept tests and the fully integrated device.
- Pump safety depends on correct external relay wiring, enclosure, isolation, and mains handling, which firmware cannot guarantee.

## Deferred decisions

- Whether approximately 25 kHz fan PWM should be revisited if noise or compatibility problems appear.
- Exact SAMD21 timer configuration and TCC0 ownership strategy if approximately 25 kHz fan PWM is adopted later.
- Final production fan PWM-to-RPM table integration from the accepted `analogWrite()` calibration data.
- Exact fallback behavior for AUTO fan mode when SHT45 is unavailable.
- Exact Home Assistant UI layout after entities are implemented and visible.
- Exact RTC alarm reconciliation behavior after `RtcClock` integration.
- Final credentials example structure when WiFi and MQTT code is introduced.

## Out of scope for v1

- Custom MQTT payload architecture.
- Full color validation with TCS34725.
- Automatic fan restart attempts.
- NeoPixel alert display.
- AVR or Arduino Mega compatibility.
- Persisting one-off manual light commands.
- Persisting pump sensor-failure override.
- EEPROM CRC validation.

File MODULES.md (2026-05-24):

# MODULES.md – Firmware module design

This document describes the intended firmware modules for the Terrarium controller.

The goal is clear module boundaries. `AutoTerraController.ino` should coordinate modules but not contain hardware or business logic.

## 1. Module overview

```text
sketches/AutoTerraController/AutoTerraController.ino

Config.h / Config.cpp
Types.h
Debug.h
Credentials.h

RtcClock.h / RtcClock.cpp
TimeSync.h / TimeSync.cpp
Persistence.h / Persistence.cpp
ModeManager.h / ModeManager.cpp
FaultManager.h / FaultManager.cpp

IRMap.h / IRMap.cpp
IRControl.h / IRControl.cpp
Fade.h / Fade.cpp
LightRuntime.h / LightRuntime.cpp
LightSensorTcs34725.h / LightSensorTcs34725.cpp

Sht45Sensor.h / Sht45Sensor.cpp
WaterTempNtc.h / WaterTempNtc.cpp
LiquidSensor.h / LiquidSensor.cpp
FanControl.h / FanControl.cpp
PumpSafety.h / PumpSafety.cpp

WiFiManager.h / WiFiManager.cpp
HomeAssistantBridge.h / HomeAssistantBridge.cpp
```

## 2. `AutoTerraController.ino`

Responsibilities:

- initialize all modules,
- call `begin()` methods,
- call periodic `update()` methods,
- keep loop non-blocking,
- avoid hardware-specific logic.

`AutoTerraController.ino` shall not:

- directly parse Home Assistant commands,
- directly read sensors except for temporary diagnostics,
- directly manipulate EEPROM,
- directly contain fallback state machine logic.

## 3. `Config.*`

Responsibilities:

- pin assignments,
- default intervals,
- default fan curves,
- default light schedule,
- default pump behavior,
- compile-time options,
- non-secret constants.

Do not store WiFi or MQTT passwords here. Use `Credentials.h`.

## 4. `Types.h`

Responsibilities:

- shared enums,
- shared structs,
- small data transfer structures,
- persistent config and runtime structure declarations.

Expected types:

- `LightMode`
- `FanMode`
- `PresetId`
- `RgbwLevel`
- `LightPreset`
- `FanCurvePoint`
- `FanCurve`
- `PersistentConfig`
- `PersistentRuntime`
- `FaultFlags`
- `ModuleAvailability`

## 5. `Debug.h`

Responsibilities:

- provide debug macros,
- make debug compile-time controlled,
- never persist debug state,
- allow module-prefixed debug messages.

Suggested macros:

```cpp
DBG_PRINT(...)
DBG_PRINTLN(...)
DBG_PRINTF(...)
DBG_MODULE(moduleName, message)
```

Debug output is useful for development but cannot be required for normal operation.

## 6. `RtcClock.*`

Responsibilities:

- initialize DS3231,
- own DS3231 INT/SQW on D2,
- reserve and prepare DS3231 32kHz input on D8,
- read current time,
- configure two DS3231 alarms for stand-alone light mode,
- read and clear alarm flags,
- report RTC availability,
- detect invalid time if possible.

The RTC alarm line uses `INPUT_PULLUP`.

The DS3231 alarms are only for stand-alone mode.

The DS3231 32kHz input on D8 is optional and prepared only. `RtcClock` shall not attach a 32kHz interrupt in v1 and shall keep 32kHz handling optional.

## 7. `TimeSync.*`

Responsibilities:

- synchronize RTC from NTP once per day,
- handle manual sync request from Home Assistant,
- keep RAM time snapshots four times per day,
- provide fallback time from last timestamp plus uptime,
- expose last sync source and sync age.

Time source priority:

1. HA/NTP
2. DS3231 RTC
3. RAM timestamp + `millis()`
4. 8h on / 16h off timer fallback for light only

## 8. `Persistence.*`

Responsibilities:

- manage AT24C32 EEPROM using JC_EEPROM,
- read persistent blobs at boot,
- validate minimal headers,
- copy EEPROM data into RAM config/runtime,
- write EEPROM on changes,
- avoid constant EEPROM reads during runtime.

Persistent storage model:

- Config blob
- Runtime blob

Header:

```text
magic
version
length
```

No CRC.

Runtime rule:

```text
RAM is the active source of truth.
EEPROM is only boot source and persistent backup.
```

## 9. `ModeManager.*`

Responsibilities:

- track active light mode,
- track active fan mode,
- detect HA timeout,
- switch to stand-alone fallback after 5 minutes,
- expose current fallback state,
- coordinate mode changes without duplicating module logic.

Important:

- light mode and fan mode are separate.
- fan manual mode remains active during HA loss.
- manual light commands are not persistent.

## 10. `FaultManager.*`

Responsibilities:

- collect faults from all modules,
- distinguish faults, warnings, and diagnostics,
- expose module availability,
- decide which local reactions are required,
- keep faults latched when appropriate,
- republish current fault state after HA reconnect.

FaultManager shall not hide hardware faults just because communication has recovered.

## 11. `IRMap.*`

Responsibilities:

- store IR address and command codes,
- store remote-button table,
- store factory preset command mapping,
- store user preset command mapping if applicable.

No timing or send logic belongs here.

## 12. `IRControl.*`

Responsibilities:

- initialize IR output,
- queue IR commands,
- send commands non-blockingly,
- enforce minimum command spacing,
- report buffer overflow.

D3 is currently assigned to the IR LED.

## 13. `Fade.*`

Responsibilities:

- compute local fade between RGBW states,
- use RGBW levels 0..10,
- support resume from elapsed time,
- report fade progress and completion,
- request IR commands through `IRControl`.

Fade does not decide why a fade starts. That belongs to LightRuntime or Schedule handling.

## 14. `LightRuntime.*`

Responsibilities:

- implement light modes,
- handle manual commands,
- handle stand-alone triggers,
- handle HA schedule triggers,
- store fade recovery data,
- decide when to use fallback,
- interact with TCS34725 validation.

Manual command behavior:

- interrupts active fade,
- lasts until next scheduled trigger,
- is not persistent.

HA schedule behavior:

- store start time, target preset, duration, start state, target state,
- resume or complete after restart if runtime data is available.

## 15. `LightSensorTcs34725.*`

Responsibilities:

- initialize TCS34725,
- own TCS34725 LED control on D4,
- initialize D4 as `OUTPUT` and set it LOW by default so the module LED is off,
- optionally use the LED later during controlled measurement modes,
- prepare D7 as optional INT input using `INPUT_PULLUP` because the INT output is open-drain,
- read Clear raw value,
- optionally read RGB, lux, and color temperature,
- perform on/off verification,
- provide current clear value for calibration,
- detect sensor availability.

Calibration values:

- off reference clear,
- minimum-on reference clear,
- global deviation threshold, initially 5%.

Events to measure:

- periodic checks,
- fade start,
- target preset reached,
- light mode change.

v1 does not depend on the TCS34725 INT pin; periodic and event-triggered measurements are sufficient.

## 16. `Sht45Sensor.*`

Responsibilities:

- initialize SHT45,
- read air temperature and humidity,
- publish or provide values at regular intervals,
- report availability,
- expose measurement error state.

No hardware alert logic exists.

Data use:

- values are published to HA,
- values are used locally by FanControl in AUTO mode.

If SHT45 is unavailable:

- publish unavailable/fault,
- AUTO fan behavior must use a defined fallback,
- MANUAL fan mode remains manual unless later explicitly changed.

## 17. `WaterTempNtc.*`

Responsibilities:

- initialize thermistor reading,
- read analog input,
- convert using NTC_Thermistor,
- provide Celsius, Fahrenheit, Kelvin,
- detect implausible values if possible,
- report availability/fault.

A0 is the assigned analog input. Divider topology, resistor value, and analog wiring are documented in `HARDWARE.md`.

## 18. `LiquidSensor.*`

Responsibilities:

- count square-wave pulses from liquid sensor,
- classify sensor level,
- compute water height in mm,
- apply 6-hour stabilization rule for noncritical level decreases,
- immediately report without-liquid state,
- report fast drop warning,
- report sensor availability.

Normal publication:

- water level in mm.

Optional diagnostics during setup, calibration, or troubleshooting:

- level,
- raw frequency.

The normal user-facing Home Assistant value is water level in mm. Internal level and raw frequency are not required for the regular dashboard unless calibration or troubleshooting requires them.

PumpSafety consumes raw or classified level for safety decisions.

## 19. `FanControl.*`

Responsibilities:

- implement AUTO and MANUAL fan modes,
- store and apply manual fan percent,
- apply temperature and humidity fan curves,
- compute effective fan percent,
- convert effective percent to inverted PWM hardware duty,
- measure two tach inputs,
- compute RPM for each fan,
- diagnose RPM faults/mismatches,
- expose values to HomeAssistantBridge.

Persistent values:

- fan mode,
- manual percent,
- fan curves,
- minimum PWM.

Important:

- PWM is output on D6 through an inverting 2N3904 NPN transistor stage.
- D6 drives the transistor base through a 2.2 kΩ resistor; the shared fan PWM node is the transistor collector.
- The blue PWM wires of both fans share the collector node with an external 2.2 kΩ pull-up to +5 V.
- The 5 V fan PWM node must not be directly connected to a Nano GPIO.
- inversion handling belongs inside `FanControl`.
- tach pull-ups are separate external 10 kΩ resistors to 3.3 V, one per tach input.
- fan 1 tach uses D9 and fan 2 tach uses D10.
- tach signals must not be tied together and must not use 5 V pull-ups.
- RPM calculation should assume two pulses per revolution unless hardware testing proves otherwise.
- one RPM table will be provided later for both fans.

## 20. `PumpSafety.*`

Responsibilities:

- control pump relay output,
- enforce critical water level cutoff,
- latch pump cutoff,
- handle sensor failure pump-off rule,
- allow manual HA release,
- ensure sensor-failure release is not persistent,
- expose pump actual/commanded/cutoff states.

Rules:

- without-liquid level triggers immediate cutoff,
- pump does not auto-restart,
- after restart, sensor-failure override must be confirmed again if sensor still fails.

## 21. `WiFiManager.*`

Responsibilities:

- connect to WiFi using WiFiNINA,
- reconnect as needed,
- expose WiFi state,
- avoid storing secrets in source files other than `Credentials.h`.

## 22. `HomeAssistantBridge.*`

Responsibilities:

- create ArduinoHA device,
- define all HA entities,
- publish values,
- receive commands,
- translate HA commands into module calls,
- publish availability,
- republish state after reconnect.

No custom MQTT payload architecture is planned for v1.

A previous test confirmed that a sensor entity can publish text-like status values in the chosen Home Assistant setup.

## 23. Update timing overview

Suggested starting intervals:

| Module | Interval / trigger |
|---|---|
| SHT45 | measure ~30 s, publish >=60 s |
| NTC | ~60 s |
| LiquidSensor | ~60 s |
| TCS34725 | periodic + light events |
| Fan RPM | frequent enough for stable RPM, design later |
| HA publish | on change + periodic heartbeat |
| RTC/NTP sync | daily + manual button |
| RAM time snapshot | four times daily |
| EEPROM write | only on changes |

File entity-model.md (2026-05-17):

# entity-model.md – Home Assistant entity model

This document defines the initial Home Assistant entity model for the terrarium controller.

The firmware shall use the `arduino-home-assistant` library and MQTT discovery.

## 1. Naming principles

Entity names should be:

- stable,
- lowercase,
- English,
- grouped by function,
- not tied to exact pin numbers.

Suggested device name:

```text
auto_terra
```

Suggested entity prefix:

```text
terrarium_
```

Example:

```text
terrarium_air_temperature
terrarium_fan1_rpm
terrarium_pump_cutoff_active
```

## 2. Sensors

### 2.1 Climate

| Entity | Type | Unit | Direction | Notes |
|---|---|---:|---|---|
| `air_temperature` | Sensor number | °C | Arduino → HA | SHT45 |
| `air_humidity` | Sensor number | % | Arduino → HA | SHT45 |
| `sht45_available` | Binary sensor | - | Arduino → HA | Availability/fault helper |
| `sht45_fault` | Binary sensor | - | Arduino → HA | true on communication/sensor fault |

### 2.2 Water temperature

| Entity | Type | Unit | Direction | Notes |
|---|---|---:|---|---|
| `water_temperature_c` | Sensor number | °C | Arduino → HA | NTC |
| `water_temperature_f` | Sensor number | °F | Arduino → HA | NTC |
| `water_temperature_k` | Sensor number | K | Arduino → HA | NTC |
| `water_temp_fault` | Binary sensor | - | Arduino → HA | ADC/thermistor fault |

### 2.3 Water level

| Entity | Type | Unit | Direction | Notes |
|---|---|---:|---|---|
| `water_level_mm` | Sensor number | mm | Arduino → HA | primary value |
| `water_level_warning` | Binary sensor | - | Arduino → HA | One level before critical; detected locally by Arduino. |
| `water_level_sensor_fault` | Binary sensor | - | Arduino → HA | invalid/unavailable sensor |
| `water_fast_drop_warning` | Binary sensor | - | Arduino → HA | lower level reached before 6h stabilization |

Optional diagnostics during setup, calibration, or troubleshooting:

| Entity | Type | Unit | Direction | Notes |
|---|---|---:|---|---|
| `water_level_raw_level` | Sensor number | - | Arduino → HA | Optional internal level diagnostic |
| `water_level_frequency` | Sensor number | Hz | Arduino → HA | Optional raw frequency diagnostic |

The normal user-facing Home Assistant value is `water_level_mm`. The optional diagnostic values are not required for the regular dashboard unless setup, calibration, or troubleshooting requires them.

### 2.4 Fans

Use one shared fan entity plus separate sensors.

| Entity | Type | Unit | Direction | Notes |
|---|---|---:|---|---|
| `fans` | Fan | % | HA ↔ Arduino | shared control in manual mode |
| `fan_mode` | Select | - | HA ↔ Arduino | AUTO / MANUAL |
| `fan_pwm_percent` | Sensor number | % | Arduino → HA | effective fan output |
| `fan_manual_percent` | Number | % | HA → Arduino | persistent manual setting |
| `fan1_rpm` | Sensor number | rpm | Arduino → HA | tach 1 |
| `fan2_rpm` | Sensor number | rpm | Arduino → HA | tach 2 |
| `fan1_fault` | Binary sensor | - | Arduino → HA | 0 rpm when expected |
| `fan2_fault` | Binary sensor | - | Arduino → HA | 0 rpm when expected |
| `fan_rpm_mismatch_warning` | Binary sensor | - | Arduino → HA | unexpected RPM compared to table |

### 2.5 Light verification

| Entity | Type | Unit | Direction | Notes |
|---|---|---:|---|---|
| `light_clear_raw` | Sensor number | - | Arduino → HA | TCS34725 clear value |
| `light_mismatch_warning` | Binary sensor | - | Arduino → HA | expected/actual mismatch |
| `light_sensor_fault` | Binary sensor | - | Arduino → HA | TCS unavailable |
| `calibrate_light_off` | Button | - | HA → Arduino | store current Clear as off |
| `calibrate_light_min_on` | Button | - | HA → Arduino | store current Clear as minimum-on |
| `light_allowed_deviation` | Number | % | HA → Arduino | default 5% |

### 2.6 RTC / time / connectivity

| Entity | Type | Unit | Direction | Notes |
|---|---|---:|---|---|
| `rtc_available` | Binary sensor | - | Arduino → HA | DS3231 ok |
| `rtc_time_valid` | Binary sensor | - | Arduino → HA | time usable |
| `last_time_sync_source` | Sensor text-like | - | Arduino → HA | NTP / RTC / RAM / TIMER |
| `last_time_sync_age` | Sensor number | s or min | Arduino → HA | age |
| `sync_time_now` | Button | - | HA → Arduino | manual NTP sync |
| `connection_drop_counter` | Sensor number | count | Arduino → HA | failed/lost HA/MQTT sessions |
| `system_status_text` | Sensor text-like | - | Arduino → HA | allowed because test succeeded |

## 3. Light control entities

| Entity | Type | Direction | Notes |
|---|---|---|---|
| `light_mode` | Select | HA ↔ Arduino | MANUAL / STANDALONE / HA_SCHEDULE |
| `current_light_preset` | Sensor or Select | Arduino → HA / HA ↔ Arduino | design later |
| `fade_active` | Binary sensor | Arduino → HA | runtime |
| `fade_progress` | Sensor number | Arduino → HA | optional |
| `manual_ir_command` | Button group / commands | HA → Arduino | map to command table |

### Stand-alone schedule

| Entity | Type | Direction | Notes |
|---|---|---|---|
| `standalone_day_time_hour` | Number | HA → Arduino | or packed UI later |
| `standalone_day_time_minute` | Number | HA → Arduino | |
| `standalone_night_time_hour` | Number | HA → Arduino | |
| `standalone_night_time_minute` | Number | HA → Arduino | |
| `standalone_day_preset` | Select | HA → Arduino | persistent |
| `standalone_night_preset` | Select | HA → Arduino | persistent |
| `standalone_fade_duration` | Number | HA → Arduino | persistent |

### HA schedule trigger

HA sends:

| Entity / action | Type | Direction | Notes |
|---|---|---|---|
| `ha_schedule_target_preset` | Select | HA → Arduino | target |
| `ha_schedule_fade_duration` | Number | HA → Arduino | duration |
| `ha_schedule_trigger_timestamp` | Number or command field | HA → Arduino | timestamp |

The exact HA UI can be finalized after firmware entities are working.

## 4. Fan curve entities

Custom MQTT is not used.

Represent curves using individual `Number` entities.

Temperature curve:

```text
fan_temp_p1_x
fan_temp_p1_y
fan_temp_p2_x
fan_temp_p2_y
fan_temp_p3_x
fan_temp_p3_y
fan_temp_p4_x
fan_temp_p4_y
```

Humidity curve:

```text
fan_hum_p1_x
fan_hum_p1_y
fan_hum_p2_x
fan_hum_p2_y
fan_hum_p3_x
fan_hum_p3_y
fan_hum_p4_x
fan_hum_p4_y
```

Default temperature curve:

```text
26 °C -> 0%
28 °C -> 20%
30 °C -> 35%
33 °C -> 50%
```

Default humidity curve:

```text
50 %RH -> 0%
65 %RH -> 20%
75 %RH -> 30%
90 %RH -> 50%
```

## 5. Pump entities

Recommended minimal model:

| Entity | Type | Direction | Notes |
|---|---|---|---|
| `pump_enable` | Switch | HA ↔ Arduino | user request / manual release |
| `pump_cutoff_active` | Binary sensor | Arduino → HA | safety cutoff latched |
| `pump_actual_state` | Binary sensor | Arduino → HA | relay commanded state |
| `water_sensor_unavailable_warning` | Binary sensor | Arduino → HA | show next to pump switch |

If the water level sensor is unavailable:

- pump is turned off,
- HA may re-enable through `pump_enable`,
- this override is not persistent,
- after Arduino restart it must be confirmed again.

## 6. Persistent configuration entities

Values set from Home Assistant and stored in EEPROM:

- light mode
- fan mode
- manual fan percent
- stand-alone schedule
- stand-alone presets
- stand-alone fade duration
- fan curves
- minimum PWM
- temperature warning thresholds
- water level calibration
- pump cutoff level
- light sensor calibration values
- user presets

## 7. Availability behavior

When a module is unavailable:

- its sensor values should be marked unavailable if the entity supports it,
- a module-specific fault binary sensor should become active,
- current state should be republished after HA reconnect.

Do not clear hardware faults merely because HA or MQTT reconnects.

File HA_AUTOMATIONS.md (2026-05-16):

# HA_AUTOMATIONS.md – Planned Home Assistant automations

This document lists automations that should live in Home Assistant rather than the Arduino firmware.

The Arduino remains responsible for hardware safety and local fallback.

## 1. HA light schedule

Home Assistant triggers scheduled light transitions in HA_SCHEDULE mode.

Each trigger sends to Arduino:

- target preset,
- fade duration,
- trigger timestamp.

The Arduino then performs the fade locally.

Possible HA implementations:

- Schedule Card,
- automations based on time helpers,
- scripts that send preset and duration values.

## 2. Water level calibration

Home Assistant shall provide a workflow to set the distance from the water level sensor top edge to the tank bottom.

The Arduino stores this value persistently and uses it to calculate water level in mm.

Possible automation:

1. user enters measured distance,
2. value is sent to Arduino,
3. Arduino stores it in RAM and EEPROM,
4. Arduino republishes calculated water level.

## 3. Light sensor calibration

Home Assistant shall provide buttons:

- save current Clear raw value as light-off reference,
- save current Clear raw value as minimum-on reference.

The Arduino performs the measurement and stores the reference values.

## 4. Time sync automation

Home Assistant dashboard exposes a button:

- manual RTC/NTP synchronization.

Arduino also performs daily NTP sync on its own.

## 5. Warning notifications

Home Assistant may create notifications for:

- water level one level before critical,
- fast water drop warning,
- water temperature out of desired limits,
- fan RPM mismatch warning,
- light expected/actual mismatch,
- pump cutoff active,
- module faults.

Hardware faults should not be cleared merely because Home Assistant reconnects.

## 6. Connection monitoring

Home Assistant can monitor the controller's availability and connection drop counter.

Arduino also tracks failed/lost MQTT/HA sessions and publishes a counter.

## 7. What should not be HA-only

These functions must remain local on Arduino:

- pump cutoff on critical level,
- pump off on water level sensor failure,
- IR command generation,
- local fade calculation,
- fan PWM generation,
- fan RPM measurement,
- sensor reads,
- fallback light mode.

## 8. Deferred automations

Do not create final automations until:

- firmware entity names are stable,
- all entities are visible in Home Assistant,
- basic sensor and control behavior has been tested.

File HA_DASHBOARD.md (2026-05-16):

# HA_DASHBOARD.md – Initial Home Assistant dashboard plan

This document describes a first dashboard concept. The final Lovelace dashboard should be written only after firmware entities are available and tested.

## 1. Dashboard goals

The dashboard shall make it easy to:

- see current environment values,
- control light mode,
- manually control light if needed,
- configure stand-alone schedule,
- configure fan mode and fan curves,
- see pump safety status,
- calibrate water level and light sensor,
- see faults and warnings.

## 2. Suggested dashboard sections

### 2.1 Overview

Show:

- air temperature,
- humidity,
- water temperature,
- water level in mm,
- current light mode,
- current fan mode,
- pump status,
- active faults/warnings.

### 2.2 Light control

Controls:

- `light_mode` select:
  - MANUAL
  - STANDALONE
  - HA_SCHEDULE

Manual control:

- buttons representing remote-control IR commands,
- preset select or preset buttons,
- optional current preset display.

Stand-alone schedule:

- day time,
- night time,
- day preset,
- night preset,
- fade duration.

HA schedule mode:

- dashboard may not directly configure everything in v1,
- HA automations or a schedule card can trigger target preset and fade duration.

### 2.3 Fan control

Show:

- shared fan entity,
- fan mode select,
- manual percent number,
- effective fan PWM percent,
- fan 1 rpm,
- fan 2 rpm,
- fan faults.

Fan curves:

- v1 can expose points as number entities.
- A nicer graph editor can be considered later.

Temperature curve default:

```text
26 °C -> 0%
28 °C -> 20%
30 °C -> 35%
33 °C -> 50%
```

Humidity curve default:

```text
50 %RH -> 0%
65 %RH -> 20%
75 %RH -> 30%
90 %RH -> 50%
```

### 2.4 Water and pump

Show:

- water level mm,
- water temperature,
- pump switch,
- pump cutoff active,
- water level sensor fault,
- water level warning,
- fast drop warning.

Important UI requirement:

If the water level sensor is unavailable, show a visible warning next to the pump switch. The pump may be manually re-enabled, but this is a conscious override and is not persistent across Arduino restarts.

### 2.5 Calibration

Controls:

- store current light clear value as off reference,
- store current light clear value as minimum-on reference,
- set allowed light deviation percent,
- set water level sensor top-to-tank-bottom distance,
- manual RTC/NTP sync button.

### 2.6 Diagnostics

Show:

- module availability,
- I²C health,
- RTC available,
- EEPROM available,
- SHT45 fault,
- TCS fault,
- NTC fault,
- fan faults,
- pump cutoff,
- connection drop counter,
- last time sync source,
- last time sync age,
- system status text.

## 3. Warning style

Warnings should be visible but not necessarily block controls.

Faults should be grouped into a clear "System Health" section.

Suggested distinction:

- red: active local safety/fault condition,
- yellow: warning or unreliable measurement,
- grey: unavailable module.

## 4. Deferred dashboard work

Do not build the final dashboard before firmware entities are available.

First priority:

1. firmware publishes all entities,
2. entity names and types are stable,
3. dashboard design follows those actual entities.

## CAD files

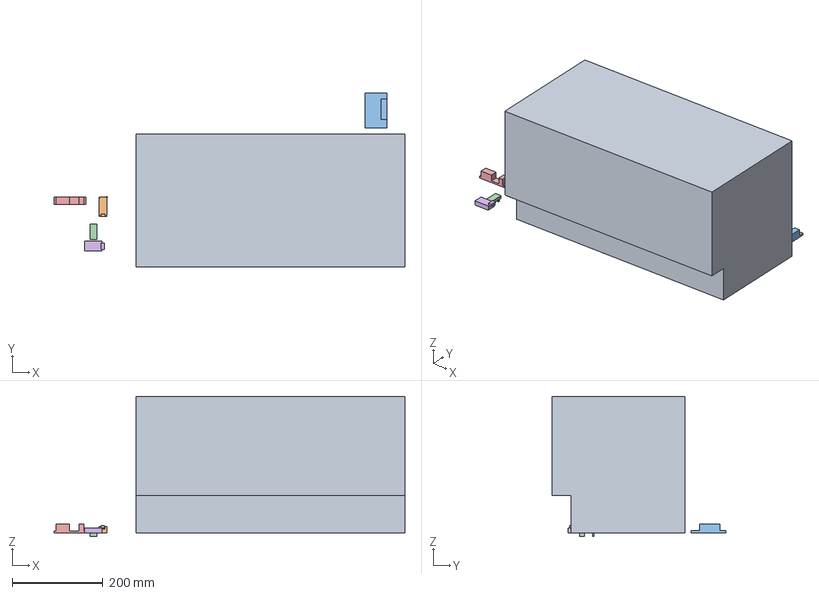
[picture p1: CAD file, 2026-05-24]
CAD/Terrarium.FCStd
772.0 x 383.3 x 308.0 mm
Terrarium
Nano
PowerSupply
SolidStateRelais
Relais
RTC

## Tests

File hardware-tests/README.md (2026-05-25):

# Hardware tests

Manual hardware validation sketches for AutoTerra live here.

These tests are separate from production firmware. They validate wiring, libraries, pin assignments, signal levels, timing behavior, and module assumptions before those assumptions are relied on by production modules.

Hardware tests normally run locally on real hardware. They can document expected compile behavior and intended Serial output, but they cannot be fully validated in CI because the relevant sensors, actuators, signal levels, and timing behavior depend on the physical build.

## Related documentation

- [`../HARDWARE.md`](../HARDWARE.md) for wiring and pin map
- [`../SPEC.md`](../SPEC.md) for functional requirements
- [`../ROADMAP.md`](../ROADMAP.md) for validation tracking
- [`../libraries.txt`](../libraries.txt) for required libraries

## Compile checks

Run `scripts/setup-arduino` once per local machine before compile checks. All
AutoTerra worktrees reuse the same shared Arduino CLI toolchain. Normal compile
checks should not download, install, or update Arduino cores or libraries.

Root/default production compile:

- Windows: `.\scripts\check-arduino.ps1`
- Linux/macOS: `./scripts/check-arduino.sh`

The default sketch is `sketches/AutoTerraController`.

Hardware test compile:

- Windows PowerShell:
  - `$env:SKETCH = "hardware-tests/i2c-bus-scan"`
  - `.\scripts\check-arduino.ps1`
- Linux/macOS: `SKETCH=hardware-tests/i2c-bus-scan ./scripts/check-arduino.sh`

Hardware test folders normally do not contain their own `sketch.yaml`; therefore the scripts compile them with `--fqbn arduino:samd:nano_33_iot`.

If a future test needs its own profile, add a local `sketch.yaml` to that test folder deliberately.

If a compile check reports that the Arduino toolchain is not prepared, run the
setup script once:

- Windows: `.\scripts\setup-arduino.ps1`
- Linux/macOS: `./scripts/setup-arduino.sh`

Set `AUTOTERRA_ARDUINO_HOME` to override the default shared toolchain location.
Worktree-local generated files can be removed with `.\scripts\cleanup-worktree.ps1`
or `./scripts/cleanup-worktree.sh`. Automatic Codex cleanup should not run
`cleanup-arduino-toolchain`; that manual script removes the shared toolchain and
requires downloads during the next setup.

## Planned test order

1. `i2c-bus-scan`
2. `rtc-ds3231-at24c32`
3. `fan-pwm-tach`
4. `fan-pwm-calibration`
5. `fan-pwm-frequency-ab`
6. `sht45`
7. `ntc-water-temp`
8. `liquid-sensor`
9. `tcs34725`
10. `pump-relay`
11. `ir-output`

## General rules

- Keep tests small.
- Cover one hardware topic per test.
- Print clear Serial output.
- Document wiring before uploading a test sketch.
- Never test mains wiring from a sketch without a safe physical setup.
- Production firmware must not depend on test-only code.
- Findings from tests should be copied back into `ROADMAP.md`, `HARDWARE.md`, `SPEC.md`, or `DECISIONS.md` when they change requirements or validate open assumptions.

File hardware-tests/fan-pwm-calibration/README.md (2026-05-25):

# Fan PWM calibration

## Purpose

- Find the minimum effective PWM percent where both fans start from stopped.
- Find the minimum effective PWM percent where already spinning fans keep running.
- Collect finer `analogWrite()`-based RPM data in 5% effective PWM steps.
- Leave space for acoustic and stability notes from the real hardware test.
- Keep final approximately 25 kHz PWM validation explicitly open.

This is a second fan hardware test. The first bring-up sketch remains in
[`../fan-pwm-tach/`](../fan-pwm-tach/) and is used to validate basic wiring,
driver inversion, and tach reading.

For comparing Arduino `analogWrite()` against approximately 25 kHz PWM, use the
separate frequency A/B sketch in [`../fan-pwm-frequency-ab/`](../fan-pwm-frequency-ab/).

## Hardware under test

- Two Noctua NF-A4x20 5V PWM fans
- 2N3904 PWM driver
- External 2.2 kOhm PWM pull-up to +5 V
- External 10 kOhm tach pull-ups to 3.3 V
- Arduino Nano 33 IoT

## Related documentation

- [`../../HARDWARE.md`](../../HARDWARE.md)
- [`../../SPEC.md`](../../SPEC.md)
- [`../../ROADMAP.md`](../../ROADMAP.md)
- [`../../libraries.txt`](../../libraries.txt)

## Sketch

- `fan-pwm-calibration.ino`

Run the compile check for this hardware test before uploading:

- Windows PowerShell:
  - `$env:SKETCH = "hardware-tests/fan-pwm-calibration"`
  - `.\scripts\check-arduino.ps1`
- Linux/macOS:
  - `SKETCH=hardware-tests/fan-pwm-calibration ./scripts/check-arduino.sh`

Upload the sketch to the Arduino Nano 33 IoT with the normal Arduino tooling,
then open Serial Monitor at `115200` baud.

## Wiring summary

- D6 -> 2.2 kOhm -> 2N3904 base
- 2N3904 emitter -> GND
- 2N3904 collector -> shared fan PWM node
- Shared fan PWM node -> 2.2 kOhm -> +5 V
- Both blue fan PWM wires -> shared fan PWM node
- Fan yellow wires -> +5 V
- Fan black wires -> common GND
- Fan 1 green tach -> D9 with 10 kOhm pull-up to 3.3 V
- Fan 2 green tach -> D10 with 10 kOhm pull-up to 3.3 V
- Common GND required

## Safety notes

- Do not connect the 5 V fan PWM node directly to a Nano GPIO.
- The fan PWM node is pulled up to 5 V but isolated from D6 by the 2N3904 collector node.
- Tach pull-ups must be 3.3 V, not 5 V.
- Fan tach outputs must remain separate and must not be tied together.
- D9 and D10 use external pull-ups only; the sketch does not enable internal pull-ups.
- Common GND is required between the Nano, fan supply, fan grounds, and transistor emitter.

## PWM inversion

The sketch works in effective fan percent and converts that value before writing
to D6 because the 2N3904 collector stage is inverting:

- effective 0% -> Arduino PWM 255
- effective 100% -> Arduino PWM 0

The Serial output prints both the effective fan percent and the Arduino PWM value
written to D6.

## Test phases

### Minimum startup test

Purpose: find the lowest effective PWM percent where both fans can start from
stopped.

- Candidates: 0%, 5%, 8%, 10%, 12%, 15%, 18%, 20%.
- Before each candidate, the sketch commands effective 0%.
- Spin-down time before each candidate: 15 seconds.
- Candidate observation time: 20 seconds.
- RPM status prints every 2 seconds.
- The summary threshold for `started` is average RPM > 100.

### Minimum stable running test

Purpose: find the lowest effective PWM percent where already spinning fans keep
running.

- The sketch spins both fans at 30% for 10 seconds before the decreasing candidate sequence.
- Candidates: 20%, 18%, 15%, 12%, 10%, 8%, 5%, 0%.
- Candidate hold time: 15 seconds.
- RPM status prints every 2 seconds.
- The summary threshold for `running` is average RPM > 100.

### 5%-step calibration sweep

Purpose: collect `analogWrite()`-based RPM data in 5% effective PWM steps.

- Steps: 0%, 5%, 10%, 15%, 20%, 25%, 30%, 35%, 40%, 45%, 50%, 55%, 60%, 65%, 70%, 75%, 80%, 85%, 90%, 95%, 100%.
- Hold time per step: 15 seconds.
- The first 6 seconds are treated as settling time.
- Summary averages use samples from the last 6 seconds of each step.
- RPM status prints every 2 seconds.

This sweep is not the final production PWM-to-RPM calibration table unless the
final PWM strategy is still equivalent after the approximately 25 kHz PWM work is
completed.

## CSV-style output

The sketch prints periodic status rows and one result row per candidate or step.
Result rows are intended to be easy to copy into a table or spreadsheet.

- `STARTUP_RESULT,percent,pwm,fan1_avg_rpm,fan2_avg_rpm,fan1_started,fan2_started`
- `RUNNING_RESULT,percent,pwm,fan1_avg_rpm,fan2_avg_rpm,fan1_running,fan2_running`
- `CAL_RESULT,percent,pwm,fan1_avg_rpm,fan2_avg_rpm,fan1_min_rpm,fan1_max_rpm,fan2_min_rpm,fan2_max_rpm`

Boolean fields use `1` for true and `0` for false.

## Assumptions and limits

- RPM calculation assumes two tach pulses per revolution unless hardware testing proves otherwise.
- This sketch uses Arduino `analogWrite()` only.
- This sketch does not validate the final approximately 25 kHz PWM requirement.
- The final production PWM-to-RPM calibration table must be repeated or confirmed after the final PWM strategy is selected.

## Result notes

Minimum startup percent:

- Both fans started from stopped at 10% effective PWM.
- Fan 1 started at 8% effective PWM, but fan 2 did not.
- Neither fan started at 0% or 5% effective PWM.

Minimum stable running percent:

- Both fans kept running at 8% effective PWM after the 30% spin-up phase.
- Fan 1 kept running at 5% effective PWM, but fan 2 stopped.
- Neither fan kept running at 0% effective PWM.

Acoustic noise notes:

No acoustic reference profile exists yet, so subjective noise should be evaluated
only in a direct comparison between the current `analogWrite()` control and the
future approximately 25 kHz PWM control. No acoustic notes were captured in this
Serial-only run.

Stability notes:

- Fan 2 needed a higher startup percent than fan 1 in this run.
- Fan 2 also stopped at 5% during the stable-running test while fan 1 continued.
- The 5% calibration step from stopped produced 0 RPM for both fans.
- The 10% calibration step started both fans and settled around 405 RPM for fan 1 and 445 RPM for fan 2.
- The final production minimum should be confirmed again after the final PWM strategy is selected.

Summary:

| Finding | Effective PWM | Arduino PWM | Notes |
|---|---:|---:|---|
| Minimum startup, both fans | 10% | 230 | Fan 1 average 441.0 RPM, fan 2 average 685.5 RPM. |
| Minimum stable running, both fans | 8% | 235 | Fan 1 average 447.9 RPM, fan 2 average 439.3 RPM. |
| Fan 1 only stable running | 5% | 243 | Fan 1 average 447.9 RPM, fan 2 stopped. |

Calibration table paste area:

```text
STARTUP_RESULT,0,255,0.0,0.0,0,0
STARTUP_RESULT,5,243,0.0,0.0,0,0
STARTUP_RESULT,8,235,450.0,0.0,1,0
STARTUP_RESULT,10,230,441.0,685.5,1,1
STARTUP_RESULT,12,225,564.0,789.0,1,1
STARTUP_RESULT,15,217,763.5,987.0,1,1
STARTUP_RESULT,18,210,915.0,1138.5,1,1
STARTUP_RESULT,20,204,1062.0,1269.0,1,1

RUNNING_RESULT,20,204,1167.9,1230.0,1,1
RUNNING_RESULT,18,210,979.3,1022.1,1,1
RUNNING_RESULT,15,217,818.6,842.1,1,1
RUNNING_RESULT,12,225,610.7,615.0,1,1
RUNNING_RESULT,10,230,460.7,467.1,1,1
RUNNING_RESULT,8,235,447.9,439.3,1,1
RUNNING_RESULT,5,243,447.9,0.0,1,0
RUNNING_RESULT,0,255,2.1,0.0,0,0

CAL_RESULT,0,255,0.0,0.0,0.0,0.0,0.0,0.0
CAL_RESULT,5,243,0.0,0.0,0.0,0.0,0.0,0.0
CAL_RESULT,10,230,405.0,445.0,405.0,405.0,435.0,450.0
CAL_RESULT,15,217,760.0,780.0,750.0,765.0,780.0,780.0
CAL_RESULT,20,204,1090.0,1125.0,1080.0,1095.0,1125.0,1125.0
CAL_RESULT,25,192,1410.0,1460.0,1410.0,1410.0,1455.0,1470.0
CAL_RESULT,30,179,1700.0,1780.0,1695.0,1710.0,1770.0,1800.0
CAL_RESULT,35,166,1985.0,2070.0,1980.0,1995.0,2070.0,2070.0
CAL_RESULT,40,153,2270.0,2355.0,2265.0,2280.0,2355.0,2355.0
CAL_RESULT,45,141,2530.0,2605.0,2520.0,2535.0,2595.0,2610.0
CAL_RESULT,50,128,2760.0,2850.0,2760.0,2760.0,2850.0,2850.0
CAL_RESULT,55,115,3025.0,3120.0,3015.0,3030.0,3120.0,3120.0
CAL_RESULT,60,102,3265.0,3370.0,3255.0,3270.0,3360.0,3390.0
CAL_RESULT,65,90,3490.0,3585.0,3480.0,3495.0,3570.0,3600.0
CAL_RESULT,70,77,3735.0,3810.0,3720.0,3750.0,3810.0,3810.0
CAL_RESULT,75,64,3940.0,4045.0,3930.0,3945.0,4035.0,4065.0
CAL_RESULT,80,51,4150.0,4250.0,4140.0,4155.0,4245.0,4260.0
CAL_RESULT,85,39,4345.0,4470.0,4335.0,4350.0,4470.0,4470.0
CAL_RESULT,90,26,4460.0,4675.0,4425.0,4500.0,4665.0,4680.0
CAL_RESULT,95,13,4650.0,4840.0,4650.0,4650.0,4830.0,4845.0
CAL_RESULT,100,0,4880.0,5090.0,4875.0,4890.0,5085.0,5100.0
```

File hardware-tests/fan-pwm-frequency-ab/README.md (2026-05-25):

# Fan PWM frequency A/B

## Purpose

- Compare Arduino `analogWrite()` fan PWM against approximately 25 kHz PWM on Arduino Nano 33 IoT / SAMD21.
- Record RPM behavior for the same practical effective PWM steps in both modes.
- Provide a place to add manual acoustic notes for each mode.
- Help decide whether `analogWrite()` is acceptable for v1 or whether production firmware should implement approximately 25 kHz fan PWM.

This test does not replace the bring-up test in [`../fan-pwm-tach/`](../fan-pwm-tach/)
or the minimum/calibration test in [`../fan-pwm-calibration/`](../fan-pwm-calibration/).

## Hardware under test

- Two Noctua NF-A4x20 5V PWM fans
- D6 shared fan PWM driver output through an inverting 2N3904 stage
- D9 fan 1 tach input
- D10 fan 2 tach input
- External 10 kOhm tach pull-ups to 3.3 V
- External fan PWM pull-up to 5 V on the isolated transistor collector node
- Arduino Nano 33 IoT

## Related documentation

- [`../../HARDWARE.md`](../../HARDWARE.md)
- [`../../SPEC.md`](../../SPEC.md)
- [`../../ROADMAP.md`](../../ROADMAP.md)
- [`../../libraries.txt`](../../libraries.txt)

## Sketch

- `fan-pwm-frequency-ab.ino`

Run the compile check for this hardware test before uploading:

- Windows PowerShell:
  - `$env:SKETCH = "hardware-tests/fan-pwm-frequency-ab"`
  - `.\scripts\check-arduino.ps1`
- Linux/macOS:
  - `SKETCH=hardware-tests/fan-pwm-frequency-ab ./scripts/check-arduino.sh`

Upload the sketch to the Arduino Nano 33 IoT with the normal Arduino tooling,
then open Serial Monitor at `115200` baud.

## Wiring summary

- D6 -> 2.2 kOhm -> 2N3904 base
- 2N3904 emitter -> GND
- 2N3904 collector -> shared fan PWM node
- Shared fan PWM node -> 2.2 kOhm -> +5 V
- Both blue fan PWM wires -> shared fan PWM node
- Fan yellow wires -> +5 V
- Fan black wires -> common GND
- Fan 1 green tach -> D9 with 10 kOhm pull-up to 3.3 V
- Fan 2 green tach -> D10 with 10 kOhm pull-up to 3.3 V
- Common GND required

## Safety notes

- Do not connect the 5 V fan PWM node directly to a Nano GPIO.
- The fan PWM node is pulled up to 5 V but isolated from D6 by the 2N3904 collector node.
- Tach pull-ups must be 3.3 V, not 5 V.
- Fan tach outputs must remain separate and must not be tied together.
- D9 and D10 use external pull-ups only; the sketch does not enable internal pull-ups.
- Common GND is required between the Nano, fan supply, fan grounds, and transistor emitter.

## PWM inversion

The sketch works in effective fan percent and converts that value before writing
to D6 because the 2N3904 collector stage is inverting:

- effective 0% -> Arduino PWM 255
- effective 100% -> Arduino PWM 0

In `analogWrite()` mode, the summary line prints the Arduino PWM value. In
approximately 25 kHz mode, it prints the TCC0 compare value used for the same
inverted command.

## A/B comparison modes

The sketch uses compile-time mode selection. This avoids fragile runtime switching
back from local TCC0 configuration to Arduino core `analogWrite()` state.

Default mode:

```cpp
#define FAN_PWM_MODE FAN_PWM_MODE_ANALOGWRITE
```

To test the approximately 25 kHz mode, change the define in the sketch to:

```cpp
#define FAN_PWM_MODE FAN_PWM_MODE_25KHZ
```

Upload once per mode, copy the `AB_RESULT` lines from Serial Monitor, and add
manual acoustic notes beside the results.

## PWM implementation

- `ANALOGWRITE` mode uses Arduino `analogWrite()` on D6.
- `25KHZ` mode uses local SAMD21 TCC0 register code for D6.
- No external timer/PWM library is used.
- The Nano 33 IoT Arduino SAMD core maps D6 to `PA04`, `TCC0/WO0`, Peripheral E.
- The 25 kHz mode uses GCLK0 at 48 MHz, TCC0 prescaler DIV1, and `PER=1919`, which targets 25,000 Hz.
- The low-level timer code is local to this hardware test sketch and is not production firmware.

If D6 does not map to the expected TCC0 channel, the sketch prints a fatal error
and does not fake 25 kHz behavior.

## Test sequence

Each upload runs the same effective PWM sequence:

```text
0%, 8%, 10%, 15%, 20%, 30%, 50%, 75%, 100%
```

- Each step is held for 12 seconds.
- The first 6 seconds are treated as settling time.
- RPM status prints every 2 seconds.
- Summary averages use samples from the last 6 seconds of each step.

The selected steps check the known low running range, the measured minimum
startup value, quiet low-to-mid operation, and higher-speed behavior.

## CSV-style output

The sketch prints one result row per step:

```text
AB_RESULT,mode,percent,pwm_or_compare_value,fan1_avg_rpm,fan2_avg_rpm,fan1_min_rpm,fan1_max_rpm,fan2_min_rpm,fan2_max_rpm,manual_noise_note
```

The `manual_noise_note` field is intentionally empty. Add notes manually after
listening, for example:

- `quiet`
- `slight ticking`
- `audible hum`
- `worse than analogWrite`
- `better than analogWrite`

Firmware does not measure sound.

## Decision criteria

Use this test to decide whether `analogWrite()` is acceptable for v1 or whether
approximately 25 kHz PWM should be implemented in production firmware.

Compare:

- acoustic behavior,
- stable operation at 8%, 10%, 15%, 20%, and 30%,
- RPM differences at the same effective percentages,
- implementation complexity and timer side effects.

The final production PWM-to-RPM calibration table must be repeated or confirmed
after the final PWM strategy is selected.

## Result notes

analogWrite acoustic notes:

No audible difference in sound profile or volume was observed compared with the
approximately 25 kHz mode.

25 kHz acoustic notes:

No audible difference in sound profile or volume was observed compared with
`analogWrite()` mode.

RPM comparison:

The A/B test ran successfully in both compile-time modes. The approximately
25 kHz mode used local TCC0 code and produced tach/RPM data on both fans.

At the same effective percent, the approximately 25 kHz mode generally produced
lower RPM than `analogWrite()` in the low-to-mid range and similar RPM in the
higher range. At 100%, the approximately 25 kHz mode was slightly higher in this
run.

Low-percent behavior differed:

- In `analogWrite()` mode, fan 1 started at 8% and fan 2 started at 10%.
- In approximately 25 kHz mode, neither fan started at 8%, fan 1 started at 10%, and both fans started at 15%.

Summary table:

| Effective PWM | analogWrite fan 1 RPM | analogWrite fan 2 RPM | 25 kHz fan 1 RPM | 25 kHz fan 2 RPM | Notes |
|---:|---:|---:|---:|---:|---|
| 0% | 0.0 | 0.0 | 0.0 | 0.0 | Both modes off. |
| 8% | 416.3 | 0.0 | 0.0 | 0.0 | Only analogWrite fan 1 moved. |
| 10% | 393.8 | 536.2 | 442.5 | 0.0 | 25 kHz fan 2 did not start. |
| 15% | 768.7 | 810.0 | 585.0 | 735.0 | Both modes ran both fans. |
| 20% | 1117.5 | 1147.5 | 930.0 | 1038.7 | 25 kHz lower. |
| 30% | 1751.2 | 1800.0 | 1638.7 | 1698.7 | 25 kHz lower. |
| 50% | 2820.0 | 2872.5 | 2752.5 | 2782.5 | Similar, 25 kHz slightly lower. |
| 75% | 3911.3 | 3956.3 | 3903.8 | 3922.5 | Very similar. |
| 100% | 4886.3 | 4957.5 | 4965.0 | 5002.5 | 25 kHz slightly higher. |

Raw result lines:

```text
AB_RESULT,ANALOGWRITE,0,255,0.0,0.0,0.0,0.0,0.0,0.0,
AB_RESULT,ANALOGWRITE,8,235,416.3,0.0,405.0,435.0,0.0,0.0,
AB_RESULT,ANALOGWRITE,10,230,393.8,536.2,390.0,405.0,465.0,690.0,
AB_RESULT,ANALOGWRITE,15,217,768.7,810.0,750.0,780.0,810.0,810.0,
AB_RESULT,ANALOGWRITE,20,204,1117.5,1147.5,1095.0,1140.0,1140.0,1155.0,
AB_RESULT,ANALOGWRITE,30,179,1751.2,1800.0,1740.0,1755.0,1770.0,1815.0,
AB_RESULT,ANALOGWRITE,50,128,2820.0,2872.5,2820.0,2820.0,2850.0,2880.0,
AB_RESULT,ANALOGWRITE,75,64,3911.3,3956.3,3885.0,3930.0,3945.0,3975.0,
AB_RESULT,ANALOGWRITE,100,0,4886.3,4957.5,4860.0,4920.0,4950.0,4965.0,

AB_RESULT,25KHZ,0,1919,0.0,0.0,0.0,0.0,0.0,0.0,
AB_RESULT,25KHZ,8,1768,0.0,0.0,0.0,0.0,0.0,0.0,
AB_RESULT,25KHZ,10,1731,442.5,0.0,420.0,465.0,0.0,0.0,
AB_RESULT,25KHZ,15,1633,585.0,735.0,570.0,600.0,660.0,885.0,
AB_RESULT,25KHZ,20,1535,930.0,1038.7,915.0,945.0,1020.0,1050.0,
AB_RESULT,25KHZ,30,1347,1638.7,1698.7,1620.0,1650.0,1680.0,1710.0,
AB_RESULT,25KHZ,50,963,2752.5,2782.5,2745.0,2760.0,2775.0,2790.0,
AB_RESULT,25KHZ,75,482,3903.8,3922.5,3885.0,3915.0,3900.0,3945.0,
AB_RESULT,25KHZ,100,0,4965.0,5002.5,4950.0,4980.0,4980.0,5010.0,
```

Final decision:

Use `analogWrite()`-based fan PWM for v1.

The A/B test showed no audible advantage for approximately 25 kHz PWM. The 25 kHz
mode also changes the PWM-to-RPM response and requires taking ownership of TCC0
on the Nano 33 IoT, so the added complexity is not justified for v1.

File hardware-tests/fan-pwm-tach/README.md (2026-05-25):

# Fan PWM and tach

## Purpose

- Verify shared fan PWM driver on D6.
- Verify inverting 2N3904 PWM stage.
- Verify fan tach inputs on D9/D10.
- Verify RPM calculation from tach pulses.
- Print effective fan percent, Arduino PWM value, pulse counts, and measured RPM.

This first manual test uses Arduino `analogWrite()` for a basic wiring and tach
bring-up. It does not validate the final approximately 25 kHz fan PWM
requirement. The final SAMD21 timer setup and PWM-to-RPM calibration table remain
separate validation tasks.

For minimum startup, minimum stable running, and finer 5% step RPM data, use the
separate calibration sketch in [`../fan-pwm-calibration/`](../fan-pwm-calibration/).

## Hardware under test

- Two Noctua NF-A4x20 5V PWM fans
- 2N3904 PWM driver
- External 2.2 kOhm PWM pull-up to +5 V
- External 10 kOhm tach pull-ups to 3.3 V
- Arduino Nano 33 IoT

## Related documentation

- [`../../HARDWARE.md`](../../HARDWARE.md)
- [`../../SPEC.md`](../../SPEC.md)
- [`../../ROADMAP.md`](../../ROADMAP.md)
- [`../../libraries.txt`](../../libraries.txt)

## Sketch

- `fan-pwm-tach.ino`

Run the compile check for this hardware test before uploading:

- Windows PowerShell:
  - `$env:SKETCH = "hardware-tests/fan-pwm-tach"`
  - `.\scripts\check-arduino.ps1`
- Linux/macOS:
  - `SKETCH=hardware-tests/fan-pwm-tach ./scripts/check-arduino.sh`

Upload the sketch to the Arduino Nano 33 IoT with the normal Arduino tooling,
then open Serial Monitor at `115200` baud.

## Wiring summary

- D6 -> 2.2 kOhm -> 2N3904 base
- 2N3904 emitter -> GND
- 2N3904 collector -> shared fan PWM node
- Shared fan PWM node -> 2.2 kOhm -> +5 V
- Both blue fan PWM wires -> shared fan PWM node
- Fan 1 green tach -> D9 with 10 kOhm pull-up to 3.3 V
- Fan 2 green tach -> D10 with 10 kOhm pull-up to 3.3 V
- Common GND required

## Pins

- D6: shared fan PWM driver output
- D9: fan 1 tach input
- D10: fan 2 tach input

## PWM inversion

The user-facing fan command is an effective fan percent. The sketch converts that
effective percent to an inverted Arduino PWM value before writing D6 because the
2N3904 collector stage inverts the signal:

- effective 0% -> Arduino PWM 255
- effective 100% -> Arduino PWM 0

The Serial output prints both the effective fan percent and the Arduino PWM value
written to D6.

## Test sequence

- The sequence repeats continuously: 0%, 15%, 25%, 50%, 75%, 100%.
- Each step is held for 10 seconds.
- Tach reports print every 2 seconds.
- RPM assumes two tach pulses per revolution unless hardware testing proves otherwise.
- Tach interrupts count falling edges on D9 and D10.
- D9 and D10 use external pull-ups only; the sketch does not enable internal pull-ups.

## Expected result

- Fans respond to effective PWM percentage.
- Tach readings are plausible.
- Both fans can be measured independently.
- Data can be used later for calibration.

## Safety notes

- Do not connect the 5 V fan PWM node directly to a Nano GPIO.
- The fan PWM node is pulled up to 5 V but isolated from D6 by the 2N3904 collector node.
- Tach pull-ups must be 3.3 V, not 5 V.
- Fan tach outputs must remain separate and must not be tied together.
- Common GND is required between the Nano, fan supply, fan grounds, and transistor emitter.

This test intentionally does not change production firmware, library versions, or
build scripts.

## Result notes

Initial manual run with `analogWrite()` confirmed that D6 inversion, the shared
PWM driver, and both separate tach inputs are functional.

- Tach interrupts attached successfully on D9 and D10.
- Effective 0% with Arduino PWM 255 stopped both fans after spin-down.
- Tach pulses were visible during spin-down after switching from 100% to 0%.
- Both fans responded to increasing effective PWM percentage.
- Fan 1 and fan 2 RPM readings were measured independently.

Approximate settled readings from two repeated stepped runs:

| Effective fan percent | Arduino PWM written to D6 | Fan 1 settled RPM | Fan 2 settled RPM | Notes |
|---:|---:|---:|---:|---|
| 0% | 255 | 0 | 0 | Fans stop after spin-down. |
| 15% | 217 | 825-840 | 855-900 | Fan 2 showed a higher transient RPM while stabilizing. |
| 25% | 192 | 1500-1530 | 1500-1530 | Both fans settled closely together. |
| 50% | 128 | 2865-2895 | 2895-2925 | Both fans settled closely together. |
| 75% | 64 | 3945-3960 | 3990-4110 | Fan 2 was slightly faster in this run. |
| 100% | 0 | 4860-5040 | 4980-5010 | Full-speed readings are plausible for the selected fans. |

These readings are not the final PWM-to-RPM calibration table because this test
uses Arduino `analogWrite()` and does not validate the final approximately
25 kHz PWM requirement.

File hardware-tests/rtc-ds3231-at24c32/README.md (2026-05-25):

# RTC DS3231 and AT24C32

## Purpose

Manual hardware test for the DS3231 RTC module with integrated AT24C32 EEPROM.

The sketch file is:

- [`rtc-ds3231-at24c32.ino`](rtc-ds3231-at24c32.ino)

This test verifies:

- DS3231 communication and current time readout.
- DS3231 lost-power status when exposed by RTClib.
- DS3231 Alarm1 / INT/SQW behavior on D2.
- Prepared DS3231 32kHz input wiring on D8 without attaching a high-frequency interrupt.
- AT24C32 EEPROM read/write through JC_EEPROM.

## Hardware under test

- DS3231 module with AT24C32
- Arduino Nano 33 IoT

## Related documentation

- [`../../HARDWARE.md`](../../HARDWARE.md)
- [`../../SPEC.md`](../../SPEC.md)
- [`../../ROADMAP.md`](../../ROADMAP.md)
- [`../../libraries.txt`](../../libraries.txt)

## Wiring summary

- A4/A5 = I2C SDA/SCL
- D2 = DS3231 INT/SQW, `INPUT_PULLUP`
- D8 = DS3231 32kHz, `INPUT_PULLUP`, optional/prepared

Expected I2C addresses:

| Address | Device |
|---|---|
| `0x68` | DS3231 RTC |
| `0x57` | AT24C32 EEPROM |

The previous `i2c-bus-scan` test already confirmed `0x68` and `0x57` on the assembled AutoTerra I2C bus. It also confirmed `0x44` for SHT45, `0x29` for TCS34725, and likely onboard Nano 33 IoT devices at `0x60` / `0x6A`.

## How to run

Baud rate:

- `115200`

Compile check:

- Windows PowerShell:
  - `$env:SKETCH = "hardware-tests/rtc-ds3231-at24c32"`
  - `.\scripts\check-arduino.ps1`
- Linux/macOS:
  - `SKETCH=hardware-tests/rtc-ds3231-at24c32 ./scripts/check-arduino.sh`

Upload the sketch to the Arduino Nano 33 IoT, then open Serial Monitor at `115200` baud.

## Sketch behavior

- Read current RTC time.
- Print whether DS3231 communication succeeded.
- Print whether the RTC reports lost power, when RTClib exposes that status.
- Leave RTC time unchanged by default.
- Optionally set RTC time from build time if the compile-time flag is deliberately changed:

```cpp
constexpr bool SET_RTC_FROM_COMPILE_TIME = false;
```

- Print a strong warning when RTC time setting is enabled.
- Clear existing alarm flags if RTC communication is available.
- Configure DS3231 INT/SQW for alarm output.
- Set Alarm1 roughly 60 seconds in the future.
- Poll D2 and the DS3231 alarm flag without attaching an interrupt handler.
- Clear and disable Alarm1 after it fires, if possible.
- Read D8 as a prepared optional 32kHz input.
- Do not attach an interrupt to D8.
- Do not count 32kHz pulses.
- Verify the AT24C32 at expected address `0x57`.
- Write and read one small test record through JC_EEPROM.
- Print RTC time and D2/D8 states every 5 seconds using `millis()`.

## EEPROM write note

This sketch writes a small test structure to the AT24C32 EEPROM once during startup.

The EEPROM test offset is:

- `0x0F00`

The AT24C32 is 32 kbit / 4096 bytes. Offset `0x0F00` is near the end of the address space and is intended to avoid future production configuration areas. The sketch does not erase the EEPROM, does not scan the full EEPROM, and does not write repeatedly in the main loop.

## Expected result

- RTC time can be read.
- Alarm/INT behavior can be observed.
- D2 reads normally HIGH and should go LOW when Alarm1 fires.
- EEPROM test data can be written and read back from `0x0F00`.
- D8 can be read as a prepared input, but is not used as an interrupt in v1.

Serial output should show:

- RTC initialization status
- current RTC time
- RTC lost-power status, if available
- D2 INT/SQW pin state
- D8 32kHz prepared input state
- alarm setup status
- alarm fired status
- EEPROM write/read verification result

## Safety notes

- Confirm the DS3231 module exposes only 3.3 V safe signals to the Nano 33 IoT.
- Do not attach interrupts to the DS3231 32kHz input for v1 validation.
- This test writes to AT24C32 EEPROM offset `0x0F00`; do not run it on hardware where that address must be preserved.

## Result notes

Manual test result, 2026-05-25:

- RTC time read succeeded.
- Example RTC time near alarm trigger: `2026-05-25 10:42:23`.
- RTC lost-power flag at startup was `false`.
- DS3231 32kHz output enabled flag at startup was `true`.
- D8 32kHz prepared input read `HIGH`; no interrupt was attached and no 32kHz pulse count was attempted.
- Alarm1 setup through RTClib succeeded.
- Before the alarm trigger, D2 INT/SQW read `HIGH`.
- At the Alarm1 trigger, the DS3231 alarm flag was set and D2 INT/SQW read `LOW`.
- After clearing and disabling Alarm1, D2 INT/SQW returned to `HIGH`.
- AT24C32 address check passed at `0x57`.
- EEPROM write/read verification passed at test offset `0x0F00`.

Open follow-up:

- 32kHz pulse behavior on D8 was not measured by this test.
- I2C and DS3231 signal voltage levels still depend on direct electrical measurement.

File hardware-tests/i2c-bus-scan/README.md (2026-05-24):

# I2C bus scan

## Purpose

- Verify the I2C bus on A4/A5.
- Detect attached I2C devices.
- Confirm that SDA/SCL pull-ups are effective and 3.3 V safe.

## Hardware under test

- Arduino Nano 33 IoT
- DS3231 RTC
- AT24C32 EEPROM
- SHT45
- TCS34725

## Related documentation

- [`../../HARDWARE.md`](../../HARDWARE.md)
- [`../../SPEC.md`](../../SPEC.md)
- [`../../ROADMAP.md`](../../ROADMAP.md)
- [`../../libraries.txt`](../../libraries.txt)

## Sketch

- [`i2c-bus-scan.ino`](i2c-bus-scan.ino)

The sketch uses only the Arduino `Wire.h` library. It initializes the Nano 33 IoT I2C bus on A4/A5, scans addresses `0x03` through `0x77`, prints detected devices, and repeats the scan every 5 seconds.

## Wiring summary

- A4 = SDA
- A5 = SCL
- Effective pull-ups to 3.3 V
- No 5 V pull-ups on SDA/SCL

## How to run

1. Confirm that SDA and SCL are pulled up only to 3.3 V.
2. Connect the Nano 33 IoT and the I2C modules with common ground.
3. Open `hardware-tests/i2c-bus-scan/i2c-bus-scan.ino` in Arduino IDE, or compile/upload it as a standalone sketch with Arduino CLI.
4. Select board `Arduino Nano 33 IoT`.
5. Upload the sketch.
6. Open Serial Monitor at `115200` baud.

## Sketch behavior

- Scan I2C addresses.
- Print detected addresses.
- Print likely or typical AutoTerra device hints for known addresses.
- Print a warning if no devices are found.
- Repeat the scan every 5 seconds using `millis()`.

## Typical address hints

Exact addresses must be confirmed on the real hardware.

| Address | Typical device |
|---|---|
| `0x29` | TCS34725 color sensor |
| `0x44` / `0x45` | SHT45 / SHT4x depending on module/address configuration |
| `0x57` | AT24C32 EEPROM |
| `0x60` | Onboard ATECC608A secure element on Nano 33 IoT |
| `0x68` | DS3231 RTC |
| `0x6A` | Onboard LSM6DS3 IMU on Nano 33 IoT |

## Expected result

- I2C devices are detected.
- Bus scan does not hang.
- Detected addresses are documented in the result notes.

## Safety notes

- Confirm that all I2C pull-ups are 3.3 V safe before connecting the bus to the Nano 33 IoT.
- Disconnect or correct any module that pulls SDA or SCL to 5 V.
- Effective pull-ups to 3.3 V are required for reliable I2C operation.

## Result notes

Manual test result:

| Address | Observed result |
|---|---|
| `0x29` | Confirmed external TCS34725 color/light sensor |
| `0x44` | Confirmed external SHT45 / SHT4x air temperature and humidity sensor |
| `0x57` | Confirmed external AT24C32 EEPROM |
| `0x60` | Likely onboard ATECC608A secure element on Nano 33 IoT |
| `0x68` | Confirmed external DS3231 RTC |
| `0x6A` | Likely onboard LSM6DS3 IMU on Nano 33 IoT |

The expected external I2C devices were found at the expected addresses. The SHT45 was confirmed at `0x44`.

`0x60` and `0x6A` are expected onboard Nano 33 IoT I2C devices and are not additional external AutoTerra modules.

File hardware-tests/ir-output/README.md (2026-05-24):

# IR output

## Purpose

- Verify IRremote output on D3.
- Confirm basic IR command sending to the terrarium lamp.
- Validate that D3 remains suitable for the IR LED driver.

## Hardware under test

- IR LED driver circuit
- Terrarium lamp receiver
- Arduino Nano 33 IoT

## Related documentation

- [`../../HARDWARE.md`](../../HARDWARE.md)
- [`../../SPEC.md`](../../SPEC.md)
- [`../../ROADMAP.md`](../../ROADMAP.md)
- [`../../libraries.txt`](../../libraries.txt)

## Wiring summary

- IR LED driver input -> D3
- D3 handled by IRremote

## Planned sketch behavior

- Send one or more known test commands.
- Keep command spacing safe.
- Print sent command names/codes.
- Confirm lamp reaction manually.

## Expected result

- Lamp reacts to known IR commands.
- D3 output works with IRremote.
- Command spacing is adequate.

## Safety notes

- Avoid rapid repeated commands that could stress the lamp controller.
- Confirm the IR LED driver circuit is wired correctly before uploading.

## Result notes

TODO: Add measured results after hardware test.

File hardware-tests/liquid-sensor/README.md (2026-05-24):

# Liquid sensor

## Purpose

- Verify CQRobot multi-point liquid level sensor frequency output.
- Confirm `INPUT_PULLUP` behavior on D5.
- Measure nominal frequencies.
- Evaluate real-world fluctuation.

## Hardware under test

- CQRobot multi-point photoelectric liquid level sensor
- Arduino Nano 33 IoT

## Related documentation

- [`../../HARDWARE.md`](../../HARDWARE.md)
- [`../../SPEC.md`](../../SPEC.md)
- [`../../ROADMAP.md`](../../ROADMAP.md)
- [`../../libraries.txt`](../../libraries.txt)

## Wiring summary

- Sensor signal -> D5
- D5 = `INPUT_PULLUP`
- Sensor output must be 3.3 V compatible

## Planned sketch behavior

- Measure frequency.
- Classify nominal states:
  - Without liquid: 20 Hz
  - Level 1: 50 Hz
  - Level 2: 100 Hz
  - Level 3: 200 Hz
  - Level 4: 400 Hz
- Print raw frequency and classified level.
- Allow collecting data for tolerance and stabilization logic.

## Expected result

- Measured frequencies roughly match documented values.
- Real fluctuation can be documented.
- Behavior near water boundaries can be observed.

## Safety notes

- Confirm the signal output is 3.3 V compatible before connecting it to D5.
- Keep sensor wiring secured before testing near water.

## Result notes

TODO: Add measured results after hardware test.

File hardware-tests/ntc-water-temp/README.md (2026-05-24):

# NTC water temperature

## Purpose

- Verify B3950 10K NTC water temperature measurement.
- Verify NTC_Thermistor library behavior.
- Check the 8.2 kOhm reference resistor divider.

## Hardware under test

- B3950 10K NTC
- 8.2 kOhm reference resistor
- Arduino Nano 33 IoT

## Related documentation

- [`../../HARDWARE.md`](../../HARDWARE.md)
- [`../../SPEC.md`](../../SPEC.md)
- [`../../ROADMAP.md`](../../ROADMAP.md)
- [`../../libraries.txt`](../../libraries.txt)

## Wiring summary

- 3.3 V -> 8.2 kOhm reference resistor -> A0 -> B3950 NTC -> GND
- AREF is not connected in v1

## Planned sketch behavior

- Read A0.
- Convert with NTC_Thermistor.
- Print Celsius, Fahrenheit, and Kelvin if supported.
- Print raw ADC value.
- Compare against a known thermometer if available.

## Expected result

- Plausible water temperature.
- Stable ADC readings.
- No need for external AREF unless later evidence shows unacceptable noise or drift.

## Safety notes

- Keep the analog divider referenced to 3.3 V and GND.
- Protect the board from water during probe handling.

## Result notes

TODO: Add measured results after hardware test.

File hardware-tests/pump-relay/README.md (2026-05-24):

# Pump relay

## Purpose

- Verify pump relay module logic input on D11.
- Verify safe default state.
- Test relay switching without mains load first.

## Hardware under test

- 3.3 V logic relay module
- Arduino Nano 33 IoT

## Related documentation

- [`../../HARDWARE.md`](../../HARDWARE.md)
- [`../../SPEC.md`](../../SPEC.md)
- [`../../ROADMAP.md`](../../ROADMAP.md)
- [`../../libraries.txt`](../../libraries.txt)

## Wiring summary

- Relay input -> D11
- D11 = `OUTPUT`
- Safe default = pump off

## Planned sketch behavior

- Initialize D11 to safe pump-off state.
- Allow controlled toggling.
- Print relay command state.
- Optionally test active-high or active-low behavior if not already known.

## Expected result

- Relay input responds predictably.
- Safe default state is confirmed.
- Active logic level is documented.

## Safety notes

- Do not test with 230 V mains load until relay wiring, enclosure, isolation, strain relief, and safety precautions are complete.
- Firmware can only command the relay; it cannot make mains wiring safe.

## Result notes

TODO: Add measured results after hardware test.

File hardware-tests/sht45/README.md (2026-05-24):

# SHT45

## Purpose

- Verify SHT45 communication with Sensirion arduino-i2c-sht4x.
- Read air temperature and humidity.
- Confirm selected I2C address.
- Observe error handling.

## Hardware under test

- SHT45 sensor
- Arduino Nano 33 IoT

## Related documentation

- [`../../HARDWARE.md`](../../HARDWARE.md)
- [`../../SPEC.md`](../../SPEC.md)
- [`../../ROADMAP.md`](../../ROADMAP.md)
- [`../../libraries.txt`](../../libraries.txt)

## Wiring summary

- A4/A5 = I2C
- 3.3 V safe supply and pull-ups

## Planned sketch behavior

- Initialize SHT45.
- Read temperature and humidity.
- Print values periodically.
- Print errors clearly.

## Expected result

- Stable temperature and humidity readings.
- Selected address documented.
- Error behavior understood.

## Safety notes

- Confirm 3.3 V safe supply and I2C pull-ups before connecting the sensor.

## Result notes

TODO: Add measured results after hardware test.

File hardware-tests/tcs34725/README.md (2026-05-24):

# TCS34725

## Purpose

- Verify TCS34725 / AngelTCS34725US communication.
- Read Clear raw value.
- Test LED control on D4.
- Prepare optional INT behavior on D7.

## Hardware under test

- AngelTCS34725US / TCS34725FN
- Arduino Nano 33 IoT

## Related documentation

- [`../../HARDWARE.md`](../../HARDWARE.md)
- [`../../SPEC.md`](../../SPEC.md)
- [`../../ROADMAP.md`](../../ROADMAP.md)
- [`../../libraries.txt`](../../libraries.txt)

## Wiring summary

- A4/A5 = I2C
- D4 = LED control, LOW off, HIGH on
- D7 = INT, open-drain, `INPUT_PULLUP`

## Planned sketch behavior

- Initialize sensor.
- Print raw Clear value.
- Optionally print RGB, lux, and color temperature.
- Toggle LED using D4.
- Observe the difference between LED off/on if useful.
- Read D7 state without depending on INT for v1.

## Expected result

- Clear raw values are readable.
- LED control works as documented.
- Useful on/off threshold behavior can be evaluated in the real room.

## Safety notes

- Confirm I2C and INT lines are 3.3 V safe.
- Avoid looking directly into bright LEDs during close-up testing.

## Result notes

TODO: Add measured results after hardware test.

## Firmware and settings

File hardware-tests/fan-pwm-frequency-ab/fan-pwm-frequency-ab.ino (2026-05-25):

#include <Arduino.h>

#if defined(ARDUINO_ARCH_SAMD)
#include "wiring_private.h"
#endif

const uint8_t PIN_FAN_PWM = 6;
const uint8_t PIN_FAN1_TACH = 9;
const uint8_t PIN_FAN2_TACH = 10;

const unsigned long SERIAL_WAIT_TIMEOUT_MS = 3000;
const unsigned long STEP_DURATION_MS = 12000;
const unsigned long REPORT_INTERVAL_MS = 2000;
const unsigned long SUMMARY_WINDOW_MS = 6000;

const uint8_t PULSES_PER_REVOLUTION = 2;
const uint8_t TEST_EFFECTIVE_PERCENTS[] = {0, 8, 10, 15, 20, 30, 50, 75, 100};
const uint8_t TEST_STEP_COUNT = sizeof(TEST_EFFECTIVE_PERCENTS) / sizeof(TEST_EFFECTIVE_PERCENTS[0]);

#define FAN_PWM_MODE_ANALOGWRITE 1
#define FAN_PWM_MODE_25KHZ 2

// Upload once with FAN_PWM_MODE_ANALOGWRITE and once with FAN_PWM_MODE_25KHZ,
// then compare the Serial output and manual acoustic notes.
#ifndef FAN_PWM_MODE
#define FAN_PWM_MODE FAN_PWM_MODE_ANALOGWRITE
#endif

#if defined(ARDUINO_ARCH_SAMD)
const uint32_t TCC0_25KHZ_PER = 1919;  // 48 MHz / (1919 + 1) = 25,000 Hz.
#endif

volatile unsigned long fan1PulseCount = 0;
volatile unsigned long fan2PulseCount = 0;

struct RpmStats {
  uint16_t sampleCount;
  float fan1Sum;
  float fan2Sum;
  float fan1Min;
  float fan1Max;
  float fan2Min;
  float fan2Max;
};

uint8_t currentStepIndex = 0;
uint8_t currentEffectivePercent = 0;
uint8_t currentArduinoPwm = 255;
uint32_t currentPwmCompareValue = 255;
unsigned long stepStartedMs = 0;
unsigned long lastReportMs = 0;
unsigned long lastFan1PulseCount = 0;
unsigned long lastFan2PulseCount = 0;
bool fatalError = false;
bool testComplete = false;
RpmStats currentStats;

void fan1TachIsr() {
  fan1PulseCount++;
}

void fan2TachIsr() {
  fan2PulseCount++;
}

uint8_t effectivePercentToArduinoPwm(uint8_t effectivePercent) {
  if (effectivePercent > 100) {
    effectivePercent = 100;
  }

  // The 2N3904 collector stage inverts the PWM signal before it reaches the fans.
  return 255 - ((static_cast<uint16_t>(effectivePercent) * 255) / 100);
}

const __FlashStringHelper* selectedModeName() {
#if FAN_PWM_MODE == FAN_PWM_MODE_25KHZ
  return F("25KHZ");
#else
  return F("ANALOGWRITE");
#endif
}

void resetStats() {
  currentStats.sampleCount = 0;
  currentStats.fan1Sum = 0.0f;
  currentStats.fan2Sum = 0.0f;
  currentStats.fan1Min = 0.0f;
  currentStats.fan1Max = 0.0f;
  currentStats.fan2Min = 0.0f;
  currentStats.fan2Max = 0.0f;
}

void addStatsSample(float fan1Rpm, float fan2Rpm) {
  if (currentStats.sampleCount == 0) {
    currentStats.fan1Min = fan1Rpm;
    currentStats.fan1Max = fan1Rpm;
    currentStats.fan2Min = fan2Rpm;
    currentStats.fan2Max = fan2Rpm;
  } else {
    if (fan1Rpm < currentStats.fan1Min) {
      currentStats.fan1Min = fan1Rpm;
    }
    if (fan1Rpm > currentStats.fan1Max) {
      currentStats.fan1Max = fan1Rpm;
    }
    if (fan2Rpm < currentStats.fan2Min) {
      currentStats.fan2Min = fan2Rpm;
    }
    if (fan2Rpm > currentStats.fan2Max) {
      currentStats.fan2Max = fan2Rpm;
    }
  }

  currentStats.sampleCount++;
  currentStats.fan1Sum += fan1Rpm;
  currentStats.fan2Sum += fan2Rpm;
}

float averageFan1Rpm() {
  if (currentStats.sampleCount == 0) {
    return 0.0f;
  }
  return currentStats.fan1Sum / static_cast<float>(currentStats.sampleCount);
}

float averageFan2Rpm() {
  if (currentStats.sampleCount == 0) {
    return 0.0f;
  }
  return currentStats.fan2Sum / static_cast<float>(currentStats.sampleCount);
}

void printFloatCsv(float value) {
  Serial.print(value, 1);
}

unsigned long readFan1Pulses() {
  noInterrupts();
  unsigned long pulses = fan1PulseCount;
  interrupts();
  return pulses;
}

unsigned long readFan2Pulses() {
  noInterrupts();
  unsigned long pulses = fan2PulseCount;
  interrupts();
  return pulses;
}

float calculateRpm(unsigned long pulses, unsigned long intervalMs) {
  if (intervalMs == 0) {
    return 0.0f;
  }

  return (static_cast<float>(pulses) * 60000.0f) /
         (static_cast<float>(PULSES_PER_REVOLUTION) * static_cast<float>(intervalMs));
}

#if defined(ARDUINO_ARCH_SAMD)
void syncTcc0() {
  while (TCC0->SYNCBUSY.reg & TCC_SYNCBUSY_MASK) {
  }
}

bool d6MapsToExpectedTcc0Channel() {
  const PinDescription& pinDescription = g_APinDescription[PIN_FAN_PWM];
  return pinDescription.ulPort == PORTA &&
         pinDescription.ulPin == 4 &&
         pinDescription.ulPWMChannel == PWM0_CH0 &&
         pinDescription.ulTCChannel == TCC0_CH0;
}

uint32_t arduinoPwmToTccCompare(uint8_t arduinoPwmValue) {
  uint32_t compare = ((static_cast<uint32_t>(arduinoPwmValue) * TCC0_25KHZ_PER) + 127) / 255;
  if (compare > TCC0_25KHZ_PER) {
    compare = TCC0_25KHZ_PER;
  }
  return compare;
}

bool configureTcc0For25KhzD6() {
  if (!d6MapsToExpectedTcc0Channel()) {
    Serial.println(F("FATAL: D6 does not map to PA04 TCC0/WO0 as expected for Arduino Nano 33 IoT."));
    Serial.println(F("25 kHz mode will not be faked."));
    return false;
  }

  PM->APBCMASK.reg |= PM_APBCMASK_TCC0;
  GCLK->CLKCTRL.reg = static_cast<uint16_t>(GCLK_CLKCTRL_CLKEN |
                                            GCLK_CLKCTRL_GEN_GCLK0 |
                                            GCLK_CLKCTRL_ID(GCM_TCC0_TCC1));
  while (GCLK->STATUS.bit.SYNCBUSY == 1) {
  }

  TCC0->CTRLA.bit.ENABLE = 0;
  syncTcc0();
  TCC0->CTRLA.bit.SWRST = 1;
  syncTcc0();
  while (TCC0->CTRLA.bit.SWRST) {
  }

  TCC0->CTRLA.reg = TCC_CTRLA_PRESCALER_DIV1;
  TCC0->WAVE.reg = TCC_WAVE_WAVEGEN_NPWM;
  syncTcc0();
  TCC0->PER.reg = TCC0_25KHZ_PER;
  syncTcc0();
  TCC0->CC[0].reg = arduinoPwmToTccCompare(currentArduinoPwm);
  syncTcc0();

  pinPeripheral(PIN_FAN_PWM, PIO_TIMER);

  TCC0->CTRLA.bit.ENABLE = 1;
  syncTcc0();
  return true;
}

void writeTcc0Duty(uint8_t arduinoPwmValue) {
  currentPwmCompareValue = arduinoPwmToTccCompare(arduinoPwmValue);
  TCC0->CTRLBSET.bit.LUPD = 1;
  syncTcc0();
  TCC0->CCB[0].reg = currentPwmCompareValue;
  syncTcc0();
  TCC0->CTRLBCLR.bit.LUPD = 1;
  syncTcc0();
}
#endif

bool configureSelectedPwmMode() {
#if FAN_PWM_MODE == FAN_PWM_MODE_25KHZ
#if defined(ARDUINO_ARCH_SAMD)
  currentPwmCompareValue = arduinoPwmToTccCompare(currentArduinoPwm);
  return configureTcc0For25KhzD6();
#else
  Serial.println(F("FATAL: 25 kHz mode is only implemented for SAMD boards in this test sketch."));
  Serial.println(F("25 kHz mode will not be faked."));
  return false;
#endif
#else
  pinMode(PIN_FAN_PWM, OUTPUT);
  analogWrite(PIN_FAN_PWM, currentArduinoPwm);
  currentPwmCompareValue = currentArduinoPwm;
  return true;
#endif
}

void applyEffectiveFanPercent(uint8_t effectivePercent) {
  currentEffectivePercent = effectivePercent;
  currentArduinoPwm = effectivePercentToArduinoPwm(effectivePercent);

#if FAN_PWM_MODE == FAN_PWM_MODE_25KHZ
#if defined(ARDUINO_ARCH_SAMD)
  writeTcc0Duty(currentArduinoPwm);
#endif
#else
  analogWrite(PIN_FAN_PWM, currentArduinoPwm);
  currentPwmCompareValue = currentArduinoPwm;
#endif
}

bool configureTachInterrupts() {
  int fan1Interrupt = digitalPinToInterrupt(PIN_FAN1_TACH);
  int fan2Interrupt = digitalPinToInterrupt(PIN_FAN2_TACH);

  if (fan1Interrupt == NOT_AN_INTERRUPT || fan2Interrupt == NOT_AN_INTERRUPT) {
    Serial.println(F("FATAL: One or both tach pins do not map to external interrupts on this board."));
    Serial.print(F("D9 interrupt number: "));
    Serial.println(fan1Interrupt);
    Serial.print(F("D10 interrupt number: "));
    Serial.println(fan2Interrupt);
    Serial.println(F("RPM will not be faked. Stopping the test at effective 0%."));
    return false;
  }

  attachInterrupt(fan1Interrupt, fan1TachIsr, FALLING);
  attachInterrupt(fan2Interrupt, fan2TachIsr, FALLING);
  Serial.println(F("Tach interrupts attached on falling edges."));
  return true;
}

void printStartupBanner() {
  Serial.println();
  Serial.println(F("AutoTerra manual hardware test: fan PWM frequency A/B"));
  Serial.println(F("Target board: Arduino Nano 33 IoT"));
  Serial.println(F("PWM pin: D6 shared fan PWM driver through inverting 2N3904 stage"));
  Serial.println(F("Tach pins: D9 fan 1 tach, D10 fan 2 tach"));
  Serial.print(F("Selected PWM mode: "));
  Serial.println(selectedModeName());

#if FAN_PWM_MODE == FAN_PWM_MODE_25KHZ
#if defined(ARDUINO_ARCH_SAMD)
  Serial.println(F("25 kHz mode: local SAMD21 TCC0 code for D6 PA04 TCC0/WO0."));
  Serial.println(F("Target PWM frequency: 25000 Hz using GCLK0 48 MHz and TCC0 PER=1919."));
#else
  Serial.println(F("25 kHz mode: unavailable on this non-SAMD build."));
#endif
#else
  Serial.println(F("25 kHz mode: not active in this upload."));
#endif

  Serial.println(F("External timer/PWM library: none."));
  Serial.println(F("Mode switching: compile-time selection. Upload once per mode and compare outputs manually."));
  Serial.println(F("WARNING: D6 uses an inverting transistor driver."));
  Serial.println(F("WARNING: The fan PWM collector node is pulled up to 5 V and must not connect directly to a Nano GPIO."));
  Serial.println(F("WARNING: D9 and D10 require external 10 kOhm pull-ups to 3.3 V. Internal pull-ups are not enabled."));
  Serial.println(F("WARNING: Tach outputs must remain separate and must not be tied together."));
  Serial.println(F("Manual acoustic perception must be recorded outside firmware."));
  Serial.println();
  Serial.println(F("STATUS,mode,percent,pwm_or_compare_value,elapsed_ms,fan1_pulses,fan1_rpm,fan2_pulses,fan2_rpm,used_for_summary"));
  Serial.println(F("AB_RESULT,mode,percent,pwm_or_compare_value,fan1_avg_rpm,fan2_avg_rpm,fan1_min_rpm,fan1_max_rpm,fan2_min_rpm,fan2_max_rpm,manual_noise_note"));
}

bool currentSampleIsUsedForSummary(unsigned long elapsedMs) {
  return elapsedMs >= (STEP_DURATION_MS - SUMMARY_WINDOW_MS);
}

void printStatusReport(unsigned long nowMs) {
  unsigned long intervalMs = nowMs - lastReportMs;
  unsigned long elapsedMs = nowMs - stepStartedMs;

  unsigned long fan1Pulses = readFan1Pulses();
  unsigned long fan2Pulses = readFan2Pulses();
  unsigned long fan1Delta = fan1Pulses - lastFan1PulseCount;
  unsigned long fan2Delta = fan2Pulses - lastFan2PulseCount;
  float fan1Rpm = calculateRpm(fan1Delta, intervalMs);
  float fan2Rpm = calculateRpm(fan2Delta, intervalMs);
  bool usedForSummary = currentSampleIsUsedForSummary(elapsedMs);

  if (usedForSummary) {
    addStatsSample(fan1Rpm, fan2Rpm);
  }

  Serial.print(F("STATUS,"));
  Serial.print(selectedModeName());
  Serial.print(F(","));
  Serial.print(currentEffectivePercent);
  Serial.print(F(","));
  Serial.print(currentPwmCompareValue);
  Serial.print(F(","));
  Serial.print(elapsedMs);
  Serial.print(F(","));
  Serial.print(fan1Delta);
  Serial.print(F(","));
  printFloatCsv(fan1Rpm);
  Serial.print(F(","));
  Serial.print(fan2Delta);
  Serial.print(F(","));
  printFloatCsv(fan2Rpm);
  Serial.print(F(","));
  Serial.print(usedForSummary ? F("1") : F("0"));
  Serial.println();

  lastReportMs = nowMs;
  lastFan1PulseCount = fan1Pulses;
  lastFan2PulseCount = fan2Pulses;
}

void printStepSummary() {
  Serial.print(F("AB_RESULT,"));
  Serial.print(selectedModeName());
  Serial.print(F(","));
  Serial.print(currentEffectivePercent);
  Serial.print(F(","));
  Serial.print(currentPwmCompareValue);
  Serial.print(F(","));
  printFloatCsv(averageFan1Rpm());
  Serial.print(F(","));
  printFloatCsv(averageFan2Rpm());
  Serial.print(F(","));
  printFloatCsv(currentStats.fan1Min);
  Serial.print(F(","));
  printFloatCsv(currentStats.fan1Max);
  Serial.print(F(","));
  printFloatCsv(currentStats.fan2Min);
  Serial.print(F(","));
  printFloatCsv(currentStats.fan2Max);
  Serial.print(F(","));
  Serial.println();
}

void beginStep(uint8_t stepIndex, unsigned long nowMs) {
  currentStepIndex = stepIndex;
  applyEffectiveFanPercent(TEST_EFFECTIVE_PERCENTS[currentStepIndex]);
  resetStats();
  stepStartedMs = nowMs;
  lastReportMs = nowMs;
  lastFan1PulseCount = readFan1Pulses();
  lastFan2PulseCount = readFan2Pulses();

  Serial.println();
  Serial.print(F("STEP_BEGIN,"));
  Serial.print(selectedModeName());
  Serial.print(F(",percent="));
  Serial.print(currentEffectivePercent);
  Serial.print(F(",pwm_or_compare_value="));
  Serial.println(currentPwmCompareValue);
}

void setup() {
  digitalWrite(PIN_FAN_PWM, HIGH);
  pinMode(PIN_FAN_PWM, OUTPUT);
  pinMode(PIN_FAN1_TACH, INPUT);
  pinMode(PIN_FAN2_TACH, INPUT);

  currentEffectivePercent = 0;
  currentArduinoPwm = effectivePercentToArduinoPwm(0);
  currentPwmCompareValue = currentArduinoPwm;

  Serial.begin(115200);
  unsigned long serialStartMs = millis();
  while (!Serial && (millis() - serialStartMs < SERIAL_WAIT_TIMEOUT_MS)) {
    // Wait briefly for the Serial Monitor without blocking standalone operation forever.
  }

  printStartupBanner();

  if (!configureSelectedPwmMode()) {
    fatalError = true;
    digitalWrite(PIN_FAN_PWM, HIGH);
    return;
  }

  applyEffectiveFanPercent(0);

  if (!configureTachInterrupts()) {
    fatalError = true;
    applyEffectiveFanPercent(0);
    return;
  }

  beginStep(0, millis());
}

void loop() {
  if (fatalError || testComplete) {
    return;
  }

  unsigned long nowMs = millis();

  if (nowMs - lastReportMs >= REPORT_INTERVAL_MS) {
    printStatusReport(nowMs);
  }

  if (nowMs - stepStartedMs >= STEP_DURATION_MS) {
    printStepSummary();
    uint8_t nextStepIndex = currentStepIndex + 1;
    if (nextStepIndex < TEST_STEP_COUNT) {
      beginStep(nextStepIndex, nowMs);
    } else {
      applyEffectiveFanPercent(0);
      Serial.println();
      Serial.println(F("TEST_COMPLETE,fan-pwm-frequency-ab"));
      Serial.println(F("Upload the other compile-time mode and compare RPM plus manual acoustic notes."));
      testComplete = true;
    }
  }
}

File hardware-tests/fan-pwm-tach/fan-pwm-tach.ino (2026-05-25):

#include <Arduino.h>

const uint8_t PIN_FAN_PWM = 6;
const uint8_t PIN_FAN1_TACH = 9;
const uint8_t PIN_FAN2_TACH = 10;

const unsigned long SERIAL_WAIT_TIMEOUT_MS = 3000;
const unsigned long STEP_DURATION_MS = 10000;
const unsigned long REPORT_INTERVAL_MS = 2000;
const uint8_t PULSES_PER_REVOLUTION = 2;

const uint8_t TEST_EFFECTIVE_PERCENTS[] = {0, 15, 25, 50, 75, 100};
const uint8_t TEST_STEP_COUNT = sizeof(TEST_EFFECTIVE_PERCENTS) / sizeof(TEST_EFFECTIVE_PERCENTS[0]);

volatile unsigned long fan1PulseCount = 0;
volatile unsigned long fan2PulseCount = 0;

uint8_t currentStepIndex = 0;
uint8_t currentEffectivePercent = 0;
uint8_t currentArduinoPwm = 255;

unsigned long currentStepStartedMs = 0;
unsigned long lastReportMs = 0;
unsigned long lastFan1PulseCount = 0;
unsigned long lastFan2PulseCount = 0;
bool tachInterruptsReady = false;

void fan1TachIsr() {
  fan1PulseCount++;
}

void fan2TachIsr() {
  fan2PulseCount++;
}

uint8_t effectivePercentToArduinoPwm(uint8_t effectivePercent) {
  if (effectivePercent > 100) {
    effectivePercent = 100;
  }

  // The 2N3904 collector stage inverts the signal before it reaches the fan PWM wire.
  return 255 - ((static_cast<uint16_t>(effectivePercent) * 255) / 100);
}

void applyEffectiveFanPercent(uint8_t effectivePercent) {
  currentEffectivePercent = effectivePercent;
  currentArduinoPwm = effectivePercentToArduinoPwm(effectivePercent);
  analogWrite(PIN_FAN_PWM, currentArduinoPwm);
}

void printStartupBanner() {
  Serial.println();
  Serial.println(F("AutoTerra manual hardware test: fan PWM and tach"));
  Serial.println(F("Target board: Arduino Nano 33 IoT"));
  Serial.println(F("PWM pin: D6 shared fan PWM driver through inverting 2N3904 stage"));
  Serial.println(F("Tach pins: D9 fan 1 tach, D10 fan 2 tach"));
  Serial.println(F("This first test uses Arduino analogWrite() and does not validate the final 25 kHz PWM requirement."));
  Serial.println(F("WARNING: D6 uses an inverting transistor driver."));
  Serial.println(F("WARNING: The fan PWM collector node is pulled up to 5 V and must not connect directly to a Nano GPIO."));
  Serial.println(F("WARNING: Tach pull-ups must be external 10 kOhm pull-ups to 3.3 V, not 5 V."));
  Serial.println(F("Tach outputs must remain separate. Do not tie fan 1 and fan 2 tach together."));
  Serial.println(F("RPM calculation assumes two tach pulses per revolution unless hardware testing proves otherwise."));
  Serial.print(F("Startup effective fan percent: "));
  Serial.print(currentEffectivePercent);
  Serial.print(F("%, Arduino PWM written to D6: "));
  Serial.println(currentArduinoPwm);
}

bool configureTachInterrupts() {
  int fan1Interrupt = digitalPinToInterrupt(PIN_FAN1_TACH);
  int fan2Interrupt = digitalPinToInterrupt(PIN_FAN2_TACH);

  if (fan1Interrupt == NOT_AN_INTERRUPT || fan2Interrupt == NOT_AN_INTERRUPT) {
    Serial.println(F("ERROR: One or both tach pins do not map to external interrupts on this board."));
    Serial.print(F("D9 interrupt number: "));
    Serial.println(fan1Interrupt);
    Serial.print(F("D10 interrupt number: "));
    Serial.println(fan2Interrupt);
    Serial.println(F("RPM will not be reported. Move no wiring unless the hardware documents are updated deliberately."));
    return false;
  }

  attachInterrupt(fan1Interrupt, fan1TachIsr, FALLING);
  attachInterrupt(fan2Interrupt, fan2TachIsr, FALLING);
  Serial.println(F("Tach interrupts attached on falling edges."));
  return true;
}

unsigned long readFan1Pulses() {
  noInterrupts();
  unsigned long pulses = fan1PulseCount;
  interrupts();
  return pulses;
}

unsigned long readFan2Pulses() {
  noInterrupts();
  unsigned long pulses = fan2PulseCount;
  interrupts();
  return pulses;
}

float calculateRpm(unsigned long pulses, unsigned long intervalMs) {
  if (intervalMs == 0) {
    return 0.0f;
  }

  return (static_cast<float>(pulses) * 60000.0f) /
         (static_cast<float>(PULSES_PER_REVOLUTION) * static_cast<float>(intervalMs));
}

void printReport(unsigned long nowMs) {
  unsigned long intervalMs = nowMs - lastReportMs;

  Serial.print(F("effective="));
  Serial.print(currentEffectivePercent);
  Serial.print(F("%, arduino_pwm="));
  Serial.print(currentArduinoPwm);

  if (tachInterruptsReady) {
    unsigned long fan1Pulses = readFan1Pulses();
    unsigned long fan2Pulses = readFan2Pulses();
    unsigned long fan1Delta = fan1Pulses - lastFan1PulseCount;
    unsigned long fan2Delta = fan2Pulses - lastFan2PulseCount;

    lastFan1PulseCount = fan1Pulses;
    lastFan2PulseCount = fan2Pulses;

    Serial.print(F(", fan1_pulses="));
    Serial.print(fan1Delta);
    Serial.print(F(", fan1_rpm="));
    Serial.print(calculateRpm(fan1Delta, intervalMs), 1);
    Serial.print(F(", fan2_pulses="));
    Serial.print(fan2Delta);
    Serial.print(F(", fan2_rpm="));
    Serial.print(calculateRpm(fan2Delta, intervalMs), 1);
  } else {
    Serial.print(F(", fan1_pulses=unsupported, fan1_rpm=unsupported"));
    Serial.print(F(", fan2_pulses=unsupported, fan2_rpm=unsupported"));
  }

  Serial.println();
}

void advanceStep(unsigned long nowMs) {
  currentStepIndex = (currentStepIndex + 1) % TEST_STEP_COUNT;
  applyEffectiveFanPercent(TEST_EFFECTIVE_PERCENTS[currentStepIndex]);
  currentStepStartedMs = nowMs;

  Serial.println();
  Serial.print(F("--- New fan step: effective="));
  Serial.print(currentEffectivePercent);
  Serial.print(F("%, Arduino PWM written to D6="));
  Serial.print(currentArduinoPwm);
  Serial.println(F(" ---"));
}

void setup() {
  digitalWrite(PIN_FAN_PWM, HIGH);
  pinMode(PIN_FAN_PWM, OUTPUT);
  pinMode(PIN_FAN1_TACH, INPUT);
  pinMode(PIN_FAN2_TACH, INPUT);

  applyEffectiveFanPercent(0);

  Serial.begin(115200);
  unsigned long serialStartMs = millis();
  while (!Serial && (millis() - serialStartMs < SERIAL_WAIT_TIMEOUT_MS)) {
    // Wait briefly for the Serial Monitor without blocking standalone operation forever.
  }

  printStartupBanner();
  tachInterruptsReady = configureTachInterrupts();

  unsigned long nowMs = millis();
  currentStepStartedMs = nowMs;
  lastReportMs = nowMs;

  Serial.println(F("Test sequence repeats continuously: 0%, 15%, 25%, 50%, 75%, 100%."));
  Serial.println(F("Each step is held for 10 seconds. Tach reports print every 2 seconds."));
}

void loop() {
  unsigned long nowMs = millis();

  if (nowMs - currentStepStartedMs >= STEP_DURATION_MS) {
    advanceStep(nowMs);
  }

  if (nowMs - lastReportMs >= REPORT_INTERVAL_MS) {
    printReport(nowMs);
    lastReportMs = nowMs;
  }
}

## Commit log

2026-05-16 Document AutoTerra and pin Arduino dependencies
2026-05-16 Document Noctua fan wiring and PWM validation
2026-05-17 Document optional TCS34725 and DS3231 signal wiring
2026-05-17 Document hardware wiring and correct NTC divider
2026-05-24 Clarify hardware wiring and I2C pull-up requirements
2026-05-24 Added wiring diagram and rudimentary CAD sketch
    [AutoTerra.fzz, Terrarium.FCStd]
2026-05-24 test: add manual i2c bus scan sketch
2026-05-24 test: document i2c bus scan results
2026-05-24 docs: record confirmed i2c scan results
2026-05-24 tooling: share Arduino CLI toolchain across worktrees
2026-05-24 tooling: verify Arduino libraries from JSON metadata
2026-05-24 tooling: configure Arduino build cache in generated config
2026-05-25 test: add fan pwm tach hardware sketch
2026-05-25 docs: record fan pwm tach test results
2026-05-25 test: add fan pwm calibration hardware sketch
2026-05-25 docs: record fan pwm calibration results
2026-05-25 docs: clarify fan acoustic evaluation
2026-05-25 test: add fan pwm frequency ab hardware sketch
2026-05-25 docs: record fan pwm frequency ab results
2026-05-25 docs: accept analogwrite fan pwm for v1
